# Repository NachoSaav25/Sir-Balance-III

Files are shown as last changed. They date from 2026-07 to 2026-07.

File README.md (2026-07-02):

# Robot Balancín — Sir Balance III
### Diseño, Fabricación y Control PID de un Péndulo Invertido Autobalanceado

Proyecto final del curso **ME4250-1 Mecatrónica** · Universidad de Chile · FCFM · DIMEC · 2026

---

## Integrantes

| Nombre |
|--------|
| A. Benjamín Castillo V. |
| Ignacio Saavedra |
| Jorge Brahim |
| Pedro Gómez |

---

## Prototipo
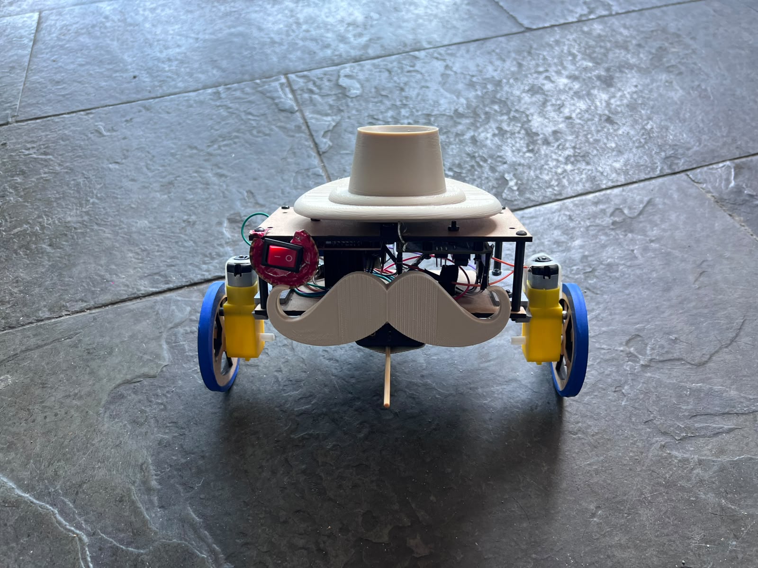
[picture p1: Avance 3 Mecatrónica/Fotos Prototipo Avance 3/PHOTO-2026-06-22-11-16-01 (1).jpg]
Sir Balance III


---

## Descripción del proyecto

Sir Balance III es un robot autobalanceado de dos ruedas que resuelve el problema del péndulo invertido, a través de un sistema inherentemente inestable que requiere control activo y continuo para mantenerse en pie. Para su desarrollo se combinó el diseño mecánico, la electrónica y teoría de control, constituyendo una plataforma de aprendizaje mecatrónico completa.

El sistema utiliza un sensor **MPU-6050** (acelerómetro + giroscopio) para medir el ángulo de inclinación en tiempo real mediante fusión sensorial con filtro complementario. Un **Arduino UNO R3** ejecuta un algoritmo **PID a 100 Hz** para mantener el equilibrio, comandando dos motores DC a través de un driver L298N. 

La estructura física fue diseñada en Fusion 360 y construida en madera con accesorios impresos en 3D, incluyendo un sombrero de copa y mostacho como estética de época y respetando de esa manera la temática rústica.

### Hardware

| Componente | Descripción |
|---|---|
| Arduino UNO R3 | Microcontrolador principal (ATmega328P, 16 MHz) |
| MPU-6050 (GY-521) | IMU: acelerómetro ±16g + giroscopio ±2000°/s, protocolo I²C |
| Driver L298N | Puente H doble para control independiente de ambos motores |
| Motor DC 6V × 2 | Con caja reductora 48:1 para torque suficiente a bajas velocidades |
| Baterías 18650 × 2 | 3350 mAh c/u, autonomía estimada ~6h 37min |

### Parámetros de control (configuración final)

| Parámetro | Valor | Descripción |
|---|---|---|
| Kp | 2,700 | Ganancia proporcional |
| Ki | 0,002 | Ganancia integral |
| Kd | 0,029 | Ganancia derivativa |
| Setpoint | 1° | Ángulo objetivo de equilibrio |
| ANGLE_DEADBAND | 0,5° | Banda muerta angular para evitar correcciones espurias |
| DEAD_ZONE_PWM | 100/255 | PWM mínimo para vencer la inercia de los motores |
| Frecuencia de loop | 100 Hz | Período de muestreo y control |

### Métricas de desempeño

| Métrica | Valor |
|---|---|
| Sobrepaso | ~15% |
| Error estacionario | ~0,4° |
| Tiempo de establecimiento | ~2,5 s |

---

## Conclusiones

Fue posible diseñar, fabricar y sintonizar exitosamente a Sir Balance III, un robot balancín de dos ruedas capaz de mantener equilibrio de forma autónoma mediante control PID. Esto fue posible gracias al método de Ziegler–Nichols, el cual entegró un punto de partida útil (Kp=2,7), aunque los valores teóricos resultaron inestables y requirieron de un ajuste iterativo manual hasta llegar a Ki=0,002 y Kd=0,029. La zona muerta de los motores (PWM≈100/255) fue un desafío crítico, resuelto con mapeo lineal de la salida PID al rango [100–255] y una banda muerta angular de 0,5°.

Asimismo, gracias a los tres avances a lo largo del semestre donde existieron estas iteraciones y cambios, se demostró que el diseño mecánico, la elección de componentes y el algoritmo de control deben ser vistas como un todo, donde cada decisión afecta el desempeño global de este robot.

---

## Referencias

[1] Mechatronic Store. *Motor DC 3V–6V con motorreductor.*
https://www.mechatronicstore.cl/motor-dc-3v-6v-con-motorreductor/

[2] Motorba. *Driver Motor Arduino L298N.*
https://motorba.com.ar/driver-motor-arduino-l298n/

[3] Descubre Arduino. *MPU6050, Diagrama de Pines, Circuito y Conexión con Arduino.*
https://descubrearduino.com/mpu6050/

[4] Descubre Arduino. *Arduino UNO R3: Qué es, Características, Precio y Pinout.*
https://descubrearduino.com/arduino-uno/

[5] PDFs Clases Auxiliares ME4250-1, 2025.

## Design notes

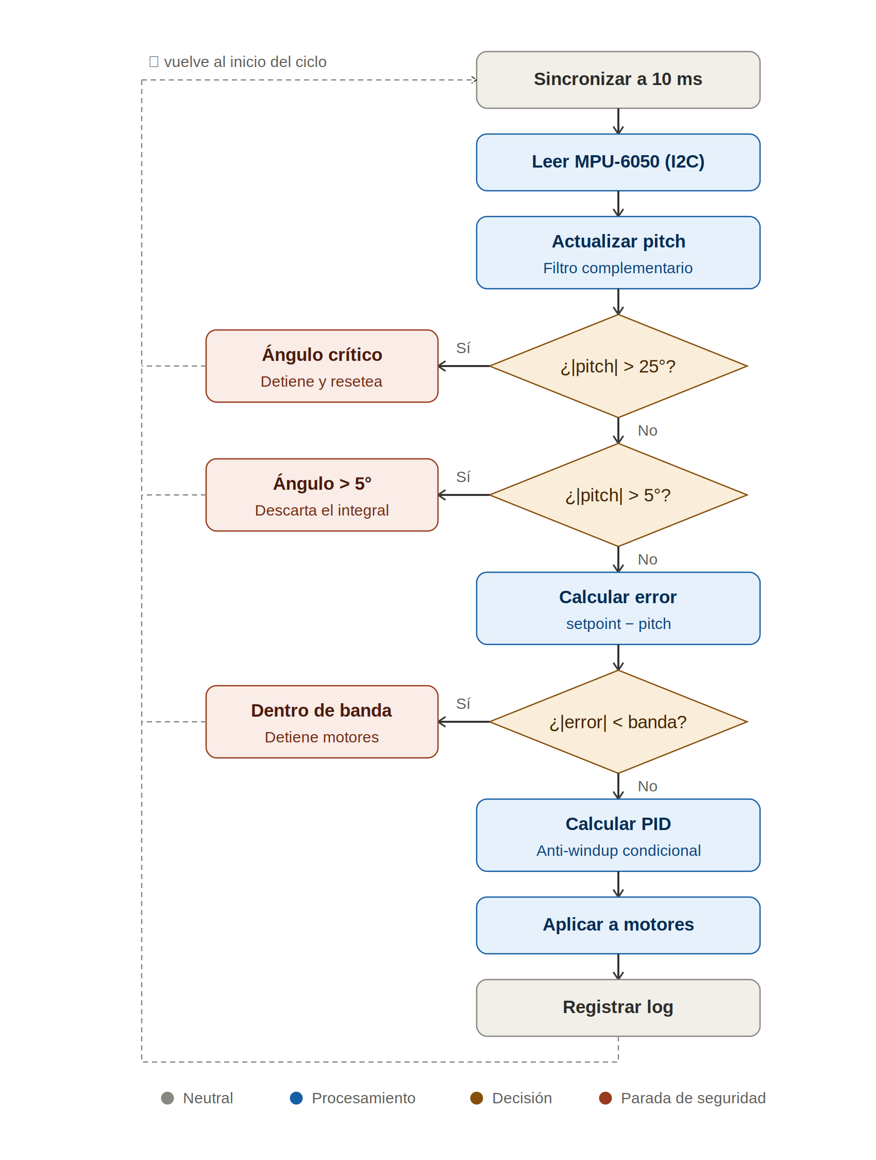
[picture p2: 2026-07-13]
diagrama de lógico o ejecución básico.png

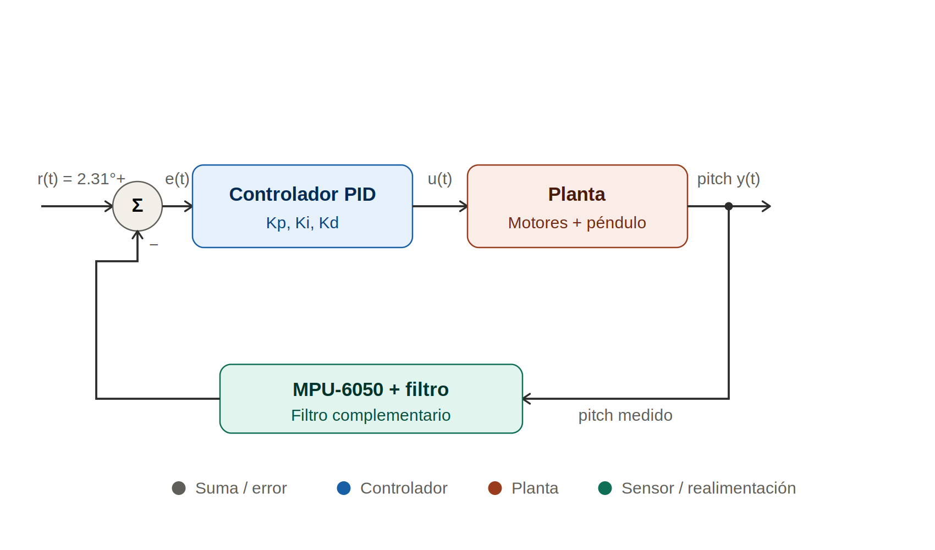
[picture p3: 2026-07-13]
Diagrama de sistema de control implementado.png

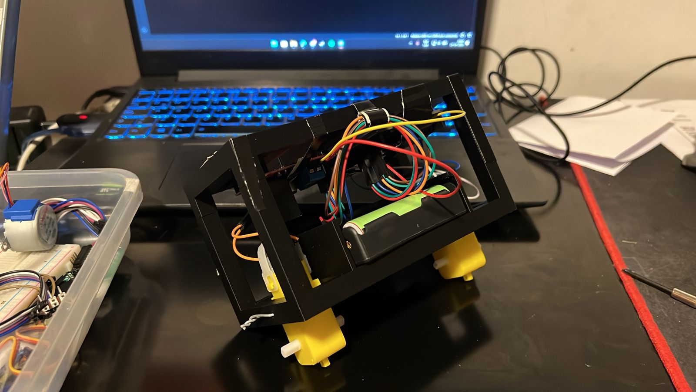
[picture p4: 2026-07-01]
Avance 1 Mecatrónica/Fotografías del prototipo avance 1/prototipo físico avance 1.jpg

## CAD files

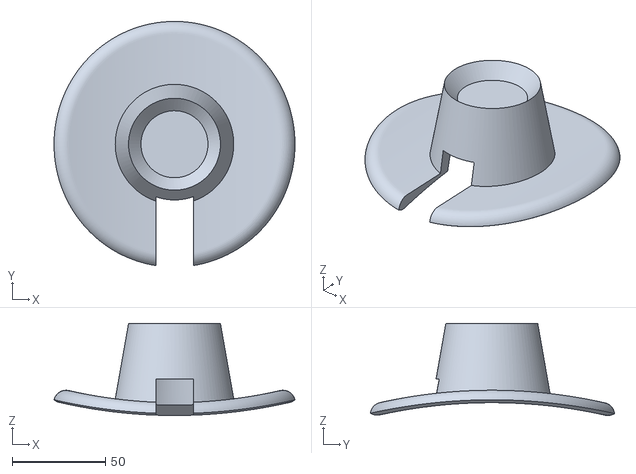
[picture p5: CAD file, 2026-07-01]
Avance 3 Mecatrónica/CAD avance 3/CowboyHat.stl
129.1 x 130.8 x 49.3

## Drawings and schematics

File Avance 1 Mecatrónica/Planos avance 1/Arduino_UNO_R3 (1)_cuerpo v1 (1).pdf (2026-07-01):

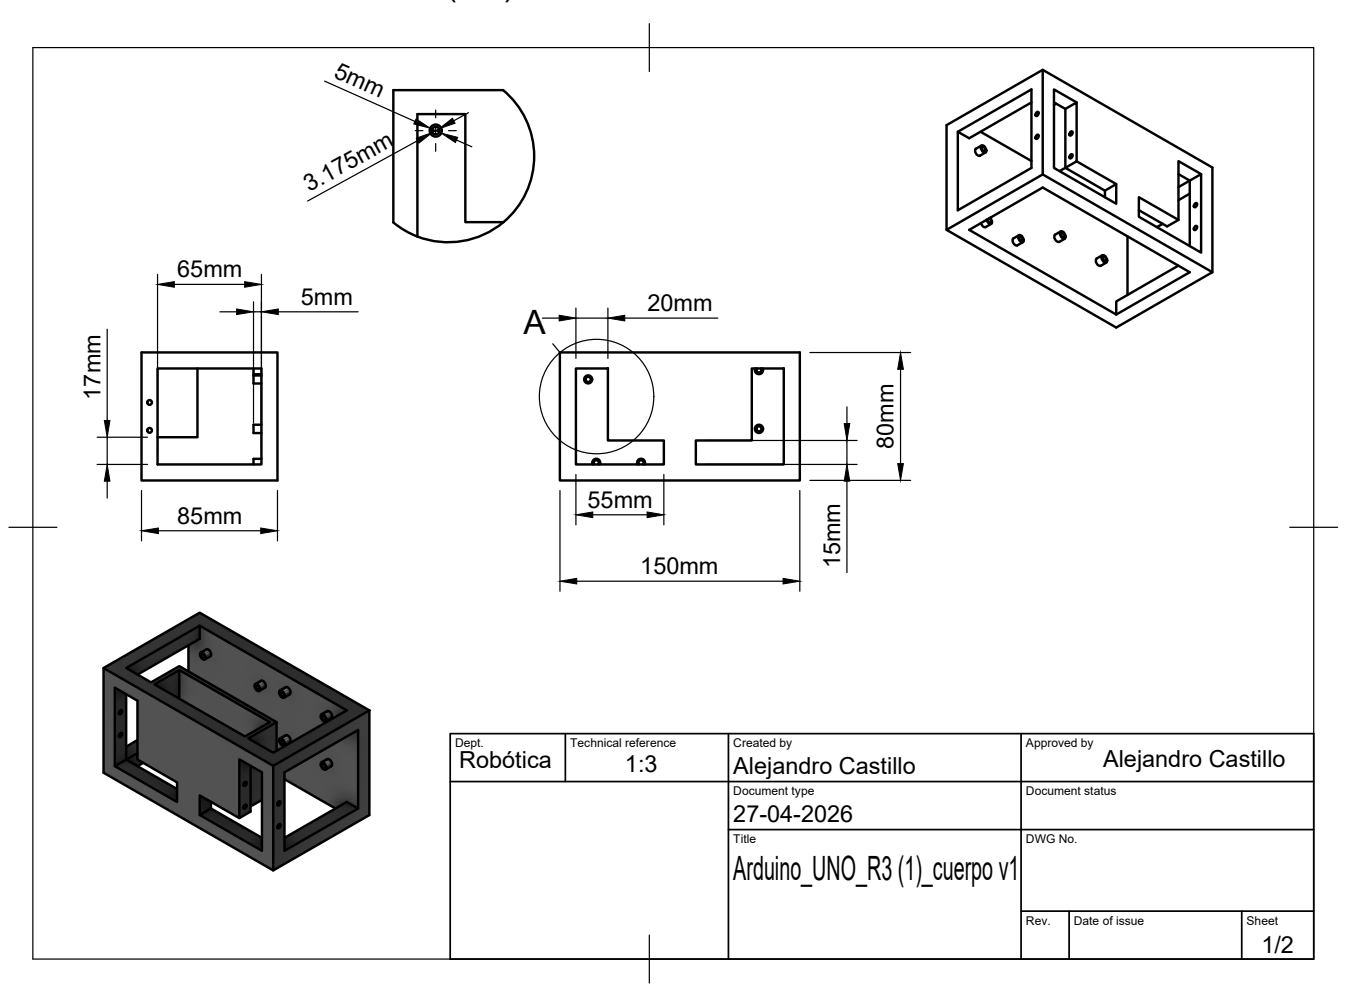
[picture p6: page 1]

Dept. Robótica | Technical reference 1:3 | Created by Alejandro Castillo | Approved by Alejandro Castillo

Document type 27-04-2026 | Document status

Title Arduino_UNO_R3 (1)_cuerpo v1 | DWG No.

Rev. | Date of issue | Sheet 1/2

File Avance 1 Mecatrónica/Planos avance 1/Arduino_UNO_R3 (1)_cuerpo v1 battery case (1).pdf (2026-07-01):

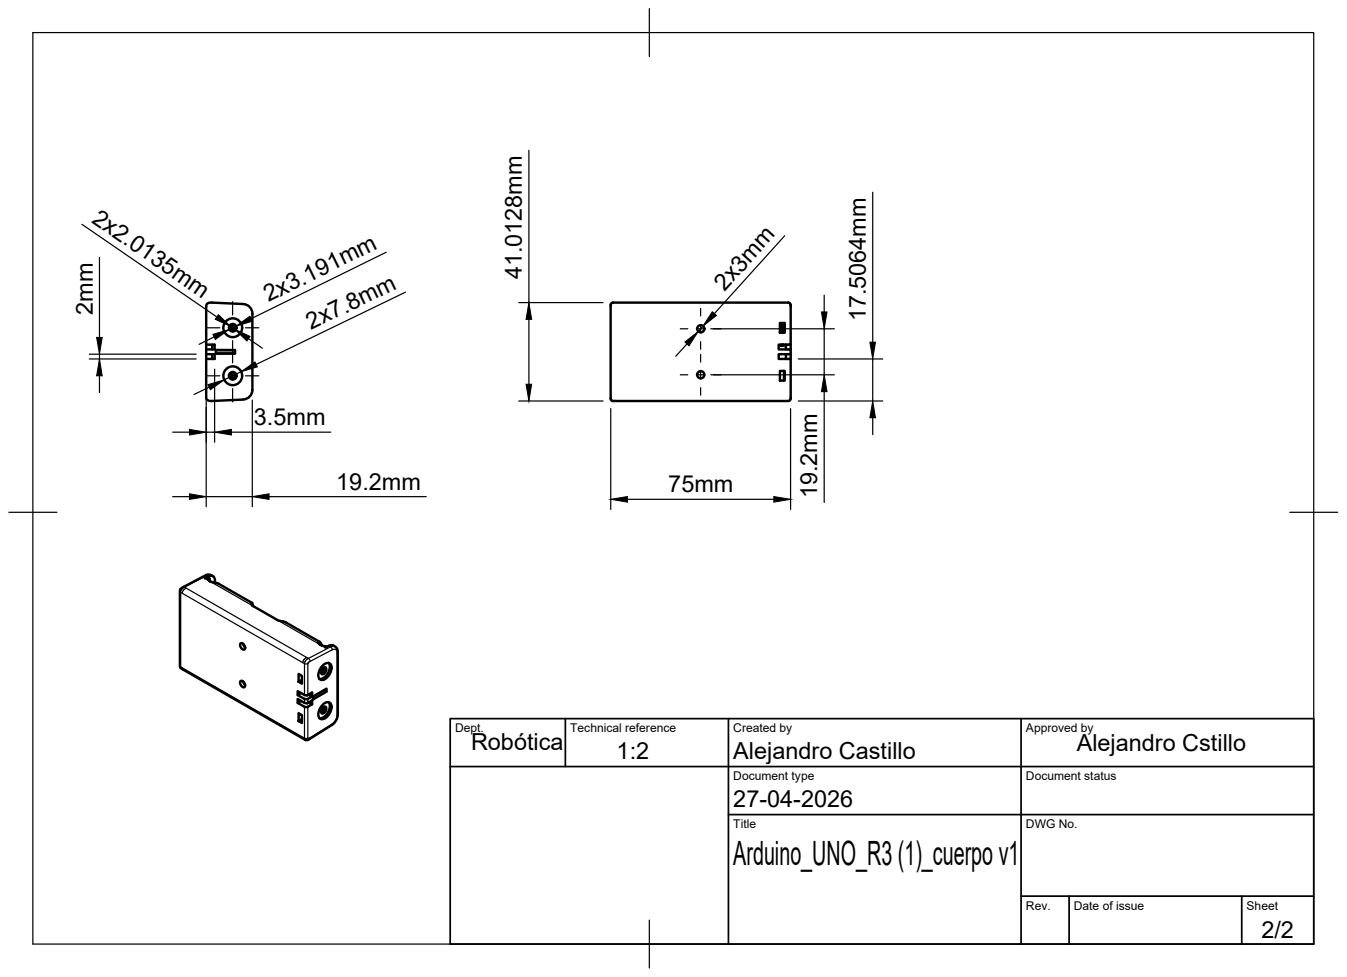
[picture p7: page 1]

Dept. | Technical reference 1:2 Robótica | Created by Alejandro Castillo | Approved by Alejandro Cstillo

Document type 27-04-2026 | Document status

Title Arduino_UNO_R3 (1)_cuerpo v1 | DWG No.

Rev. | Date of issue | Sheet 2/2

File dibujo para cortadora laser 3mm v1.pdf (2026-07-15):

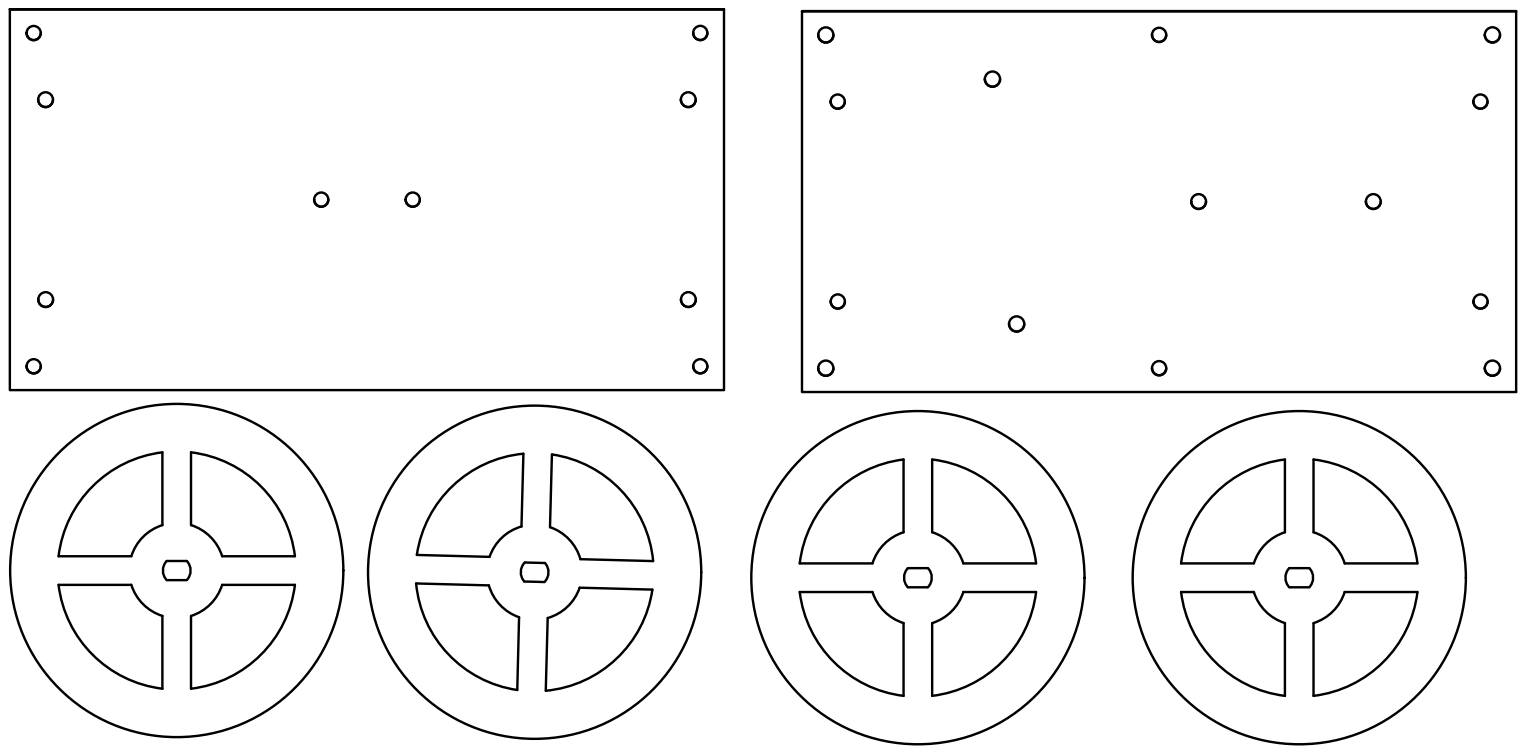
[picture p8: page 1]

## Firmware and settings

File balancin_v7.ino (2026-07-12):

#include <Wire.h>

// ═══════════════════════════════════════════════════════════
// VARIABLES DE CONTROL
// ═══════════════════════════════════════════════════════════

const unsigned long LOOP_DT_MS = 10;

const float COMP_ALPHA = 1;

float Kp = 35;
float Ki = 40;;
float Kd = 0.5;
float setpoint = 2.31;
const float INTEGRAL_LIMIT = 100;
const int DEAD_ZONE_PWM = 0;
const float ANGLE_DEADBAND = 0;
const float MAX_ANGLE = 25.0;

// --- Anti-windup (v7) ---
// Solo se integra cuando el error es pequeno (cerca del equilibrio).
// En errores grandes, P y D hacen el trabajo y la I no acumula sesgo.
const float INTEGRAL_ACTIVE_BAND = 5.0;   // grados
// Si el pitch se pasa de este angulo, se descarta la integral acumulada.
const float INTEGRAL_RESET_ANGLE = 5.0;  // grados

// ═══════════════════════════════════════════════════════════
// VARIABLES DE HARDWARE
// ═══════════════════════════════════════════════════════════

// MPU-6050
const int MPU_ADDR = 0x68;
const float GYRO_SENS = 131.0;

// L298N — Motor A (izquierdo)
const int enA = 9;
const int in1 = 8;
const int in2 = 7;

// L298N — Motor B (derecho)
const int enB = 3;
const int in3 = 5;
const int in4 = 4;

// PWM

const int MAX_PWM = 255;

// ═══════════════════════════════════════════════════════════
// ESTADO GLOBAL
// ═══════════════════════════════════════════════════════════

int16_t ax, ay, az;
int16_t gx, gy, gz;
float gx_offset = 0, gy_offset = 0, gz_offset = 0;

float pitch = 0.0;
float gyroPitchRate = 0.0;

float integral = 0.0;
float errorPrev = 0.0;

unsigned long lastTime;
unsigned long nextLoop = 0;
float dt;

int currentSpeed = 0;

// ═══════════════════════════════════════════════════════════
// SETUP
// ═══════════════════════════════════════════════════════════

void setup() {
  Serial.begin(115200);

  setupMotors();
  setupMPU();

  Serial.println(F("Calibrando... manten el robot quieto."));
  delay(1500);
  calibrateGyro();
  Serial.println(F("Calibracion completa."));

  readMPU6050();
  pitch = computeAccelPitch();
  errorPrev = setpoint - pitch;

  lastTime = millis();
  nextLoop = millis() + LOOP_DT_MS;
}

// ═══════════════════════════════════════════════════════════
// LOOP PRINCIPAL
// ═══════════════════════════════════════════════════════════

void loop() {
  if (millis() < nextLoop) return;
  nextLoop += LOOP_DT_MS;

  readMPU6050();

  unsigned long now = millis();
  dt = (now - lastTime) / 1000.0;
  lastTime = now;

  updatePitch();

  // Corte de seguridad por ángulo extremo
  if (abs(pitch) > MAX_ANGLE) {
    stopMotors();
    integral = 0;
    errorPrev = setpoint - pitch;
    logState();
    return;
  }

  // Reset de integral en ángulo crítico: si ya estamos muy inclinados,
  // el windup acumulado juega en contra. Lo soltamos.
  if (abs(pitch) > INTEGRAL_RESET_ANGLE) {
    integral = 0;
  }

  float error = setpoint - pitch;

  // Zona muerta angular: no corregir desvíos pequeños
  if (abs(error) < ANGLE_DEADBAND) {
    stopMotors();
    errorPrev = error;
    logState();
    return;
  }

  float output = computePID(error);
  applyMotors(output);
  logState();
}

// ═══════════════════════════════════════════════════════════
// PID
// ═══════════════════════════════════════════════════════════

float computePID(float error) {
  // Conditional integration (anti-windup): solo acumular cuando
  // el error es pequeño. En desvíos grandes, P y D hacen el trabajo.
  if (abs(error) < INTEGRAL_ACTIVE_BAND) {
    integral += error * dt;
    integral = constrain(integral, -INTEGRAL_LIMIT, INTEGRAL_LIMIT);
  }

  float derivative = (error - errorPrev) / dt;
  errorPrev = error;

  return Kp * error + Ki * integral + Kd * derivative;
}

// ═══════════════════════════════════════════════════════════
// MOTORES
// ═══════════════════════════════════════════════════════════

void setupMotors() {
  pinMode(enA, OUTPUT); pinMode(enB, OUTPUT);
  pinMode(in1, OUTPUT); pinMode(in2, OUTPUT);
  pinMode(in3, OUTPUT); pinMode(in4, OUTPUT);
  stopMotors();
}

void applyMotors(float output) {
  float mag = abs(output);
  if (mag > 255.0) mag = 255.0;

  // Mapeo lineal [0, 255] → [DEAD_ZONE_PWM, MAX_PWM]
  int speed = DEAD_ZONE_PWM + (int)(mag * (MAX_PWM - DEAD_ZONE_PWM) / 255.0);
  speed = constrain(speed, DEAD_ZONE_PWM, MAX_PWM);

  if (output > 0) {
    digitalWrite(in1, HIGH); digitalWrite(in2, LOW);
    digitalWrite(in3, LOW); digitalWrite(in4, HIGH);
    currentSpeed = speed;
  } else {
    digitalWrite(in1, LOW);  digitalWrite(in2, HIGH);
    digitalWrite(in3, HIGH);  digitalWrite(in4, LOW);
    currentSpeed = -speed;
  }

  analogWrite(enA, speed);
  analogWrite(enB, speed);
}

void stopMotors() {
  digitalWrite(in1, LOW); digitalWrite(in2, LOW);
  digitalWrite(in3, LOW); digitalWrite(in4, LOW);
  analogWrite(enA, 0);
  analogWrite(enB, 0);
  currentSpeed = 0;
}

// ═══════════════════════════════════════════════════════════
// MPU-6050
// ═══════════════════════════════════════════════════════════

void setupMPU() {
  Wire.begin();
  Wire.setClock(400000);

  // Despertar el MPU
  Wire.beginTransmission(MPU_ADDR);
  Wire.write(0x6B);
  Wire.write(0);
  Wire.endTransmission(true);

  // Activar DLPF interno (~44 Hz BW)
  Wire.beginTransmission(MPU_ADDR);
  Wire.write(0x1A);
  Wire.write(0x03);
  Wire.endTransmission(true);
}

void readMPU6050() {
  Wire.beginTransmission(MPU_ADDR);
  Wire.write(0x3B);
  Wire.endTransmission(false);
  Wire.requestFrom(MPU_ADDR, 14, true);

  ax = Wire.read() << 8 | Wire.read();
  ay = Wire.read() << 8 | Wire.read();
  az = Wire.read() << 8 | Wire.read();
  Wire.read(); Wire.read();
  gx = Wire.read() << 8 | Wire.read();
  gy = Wire.read() << 8 | Wire.read();
  gz = Wire.read() << 8 | Wire.read();
}

void calibrateGyro() {
  long sumX = 0, sumY = 0, sumZ = 0;
  const int samples = 3000;

  for (int i = 0; i < samples; i++) {
    readMPU6050();
    sumX += gx;
    sumY += gy;
    sumZ += gz;
    delay(3);
  }

  gx_offset = (float)sumX / samples;
  gy_offset = (float)sumY / samples;
  gz_offset = (float)sumZ / samples;

  Serial.print(F("Offsets - gx: ")); Serial.print(gx_offset);
  Serial.print(F("  gy: "));         Serial.print(gy_offset);
  Serial.print(F("  gz: "));         Serial.println(gz_offset);
}

float computeAccelPitch() {
  float ax_f = (float)ax;
  float ay_f = (float)ay;
  float az_f = (float)az;

  float denom = sqrt(ay_f * ay_f + az_f * az_f);
  if (denom < 0.0001) denom = 0.0001;

  return atan2(-ax_f, denom) * 180.0 / PI;
}

void updatePitch() {
  gyroPitchRate = ((float)gy - gy_offset) / GYRO_SENS;
  float accelPitch = computeAccelPitch();
  pitch = COMP_ALPHA * (pitch + gyroPitchRate * dt)
        + (1.0 - COMP_ALPHA) * accelPitch;
}

// ═══════════════════════════════════════════════════════════
// LOG
// ═══════════════════════════════════════════════════════════

void logState() {
  static byte counter = 0;
  if (++counter < 5) return;
  counter = 0;

  Serial.print(F("Pitch:"));  Serial.print(pitch, 2);
  Serial.print(F(" gRate:")); Serial.print(gyroPitchRate, 2);
  Serial.print(F(" PWM:"));   Serial.println(currentSpeed);
  Serial.print(F(" Setpo:"));   Serial.println(setpoint);
}
